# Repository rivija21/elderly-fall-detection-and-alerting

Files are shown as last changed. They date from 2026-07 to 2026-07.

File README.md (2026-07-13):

# Non-Invasive Elderly Fall Detection System

## Overview
This repository contains the firmware, hardware schematics, and mechanical design files for a privacy-preserving, non-invasive bathroom fall detection unit. 

Designed specifically to operate without the use of cameras, this system ensures complete user privacy in sensitive environments. It achieves high-accuracy fall detection by integrating a 60GHz mmWave radar sensor with an ESP32-S3 microcontroller, complemented by a verbal cancellation logic mechanism to rigorously filter false positive alerts.

## Key Features
* **Privacy-First Sensing:** Utilizes 60GHz mmWave radar, eliminating the need for optical cameras.
* **Edge Processing:** All signal processing and fall detection algorithms are executed locally on the ESP32-S3.
* **Verbal Cancellation Logic:** Integrates audio-based confirmation to prevent unnecessary emergency alerts in the event of a false trigger.
* **Custom Enclosure:** 3D-printable housing designed for optimal sensor positioning and environmental protection.

## System Hardware
* **Microcontroller:** ESP32-S3
* **Radar Sensor:** SEN0623 (60GHz mmWave)
* **TPS21 IP2326 based BMS**
* **A impedence matched INMP441 with 4ohm 3W speaker setup**

## Hardware Visuals

### Printed Enclosure
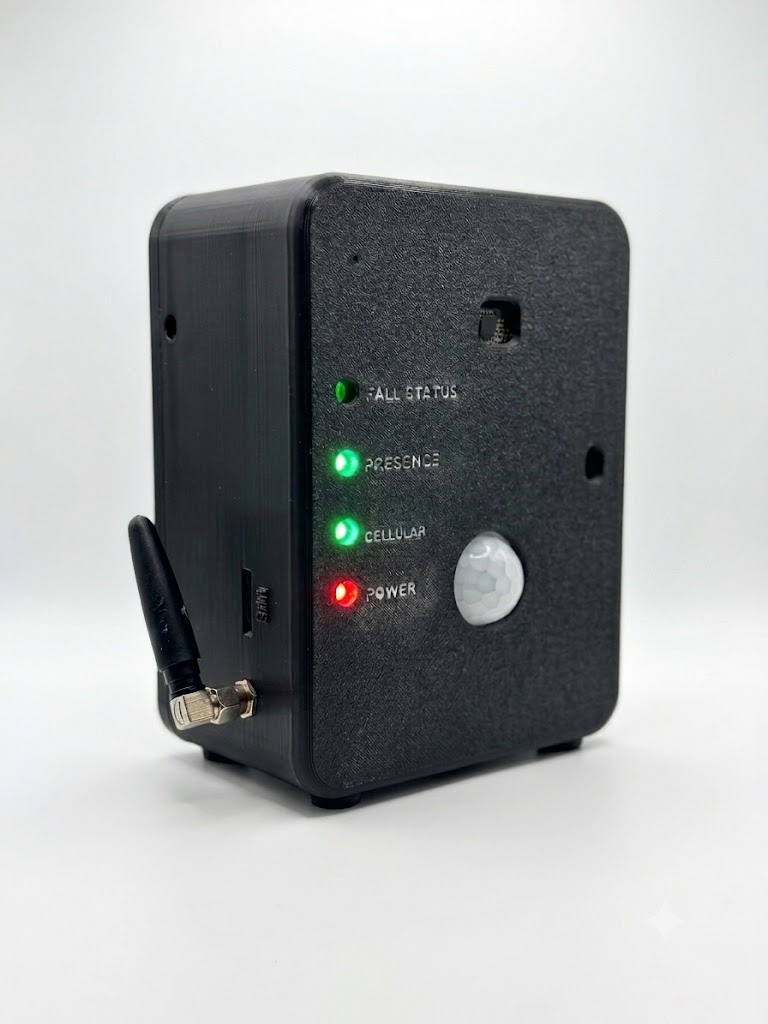
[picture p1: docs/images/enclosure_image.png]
Fully Assembled 3D Printed Enclosure


### PCB Assembly
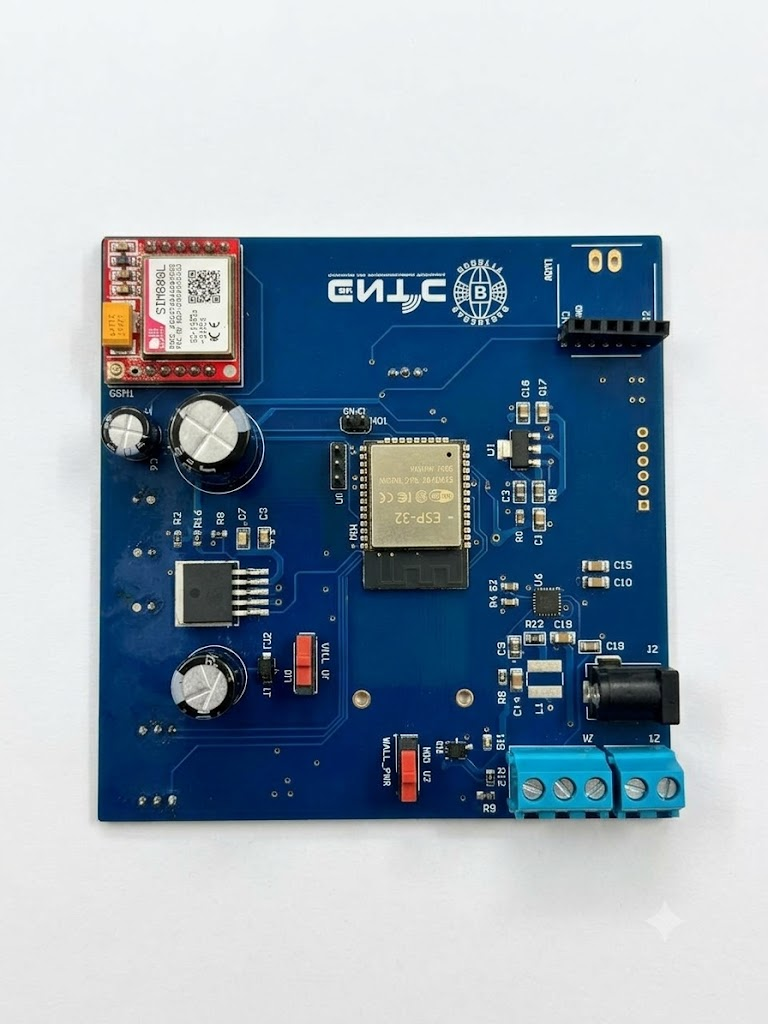
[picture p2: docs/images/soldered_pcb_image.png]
Soldered PCB Configuration


## Repository Structure
```text
elderly-fall-detection/
├── Firmware/       # ESP32-S3 source code and build files
├── Hardware/       # Schematics, PCB layouts, and BOM
├── Mechanical/     # STL files for 3D printing the enclosure
└── Docs/           # Final engineering design project report and diagrams

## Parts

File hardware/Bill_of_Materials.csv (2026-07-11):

Category | Part | Supplier | Qty | Unit Cost (USD) | Bulk Cost (USD) [5000 units]
Microcontroller | ESP32-WROOM-32E | LCSC | 1 | 3.98 | 2.89
Capacitor | 0.1uF | LCSC | 1 | 0.02 | 0.01
Capacitor | 1uF | LCSC | 3 | 0.02 | 0.01
Capacitor | 10uF | LCSC | 4 | 0.04 | 0.03
Capacitor | 22uF | LCSC | 9 | 0.1 | 0.08
Capacitor | 47uF | LCSC | 1 | 0.15 | 0.1
Capacitor | 100uF | LCSC | 1 | 0.5 | 0.3
Capacitor | 330uF | LCSC | 1 | 0.9 | 0.65
Resistor | 100Ω | LCSC | 1 | 0.01 | 0.002
Resistor | 330Ω | LCSC | 2 | 0.01 | 0.002
Resistor | 470Ω | LCSC | 2 | 0.01 | 0.002
Resistor | 1kΩ | LCSC | 1 | 0.01 | 0.002
Resistor | 10kΩ | LCSC | 3 | 0.01 | 0.002
Resistor | 20kΩ | LCSC | 3 | 0.01 | 0.002
Resistor | 33kΩ | LCSC | 1 | 0.01 | 0.002
Resistor | 43kΩ | LCSC | 1 | 0.01 | 0.002
Resistor | 51kΩ | LCSC | 1 | 0.01 | 0.002
Resistor | 100kΩ | LCSC | 3 | 0.01 | 0.002
Resistor | 180kΩ | LCSC | 1 | 0.01 | 0.002
Inductor | 2.2uH | TBD | 1
Connector | 2-hole screw terminal | LCSC | 1 | 0.04 | 0.02
Connector | 3-hole screw terminal | LCSC | 1 | 0.05 | 0.03
Connector | Barrel jack | LCSC | 1 | 0.04 | 0.02
MOSFET | AO341A | LCSC | 1 | 0.02 | 0.01
MOSFET | BSS138 | LCSC | 1 | 0.01 | 0.005
Regulator | MIC2302WU | LCSC | 1 | 0.35 | 0.25
Regulator | AMS1117 | LCSC | 2 | 0.04 | 0.02
IC | TPS2121RUXT | LCSC | 1 | 1.2 | 1
IC | IP2326 | LCSC | 2 | 0.45 | 0.35
LED | NeoPixel strip (8 LEDs) | LCSC | 1 | 1.5 | 0.5
Sensor | MAX98357 | LCSC | 1 | 1.44 | 0.6
Sensor | SIM800L | LCSC | 1 | 3.27 | 1.49
Sensor | HC-SR501 | LCSC | 1 | 0.77 | 0.3
Sensor | SEN0623 | LCSC | 1 | 35 | 21
Sensor | INMP441 | LCSC | 1 | 2.6 | 1
Sensor | VL53L1X | LCSC | 1 | 2.98 | 1.78
Mechanical | Enclosure | MS 3D Printing | 1 | 11.94 | 5.5
PCB | 100x100 mm PCB | JLCPCB | 1 | 5.37 | 2.5
total |  |  |  | 67.07 | 36.375
all prices in USD
tax should also be considered
11/7/2026

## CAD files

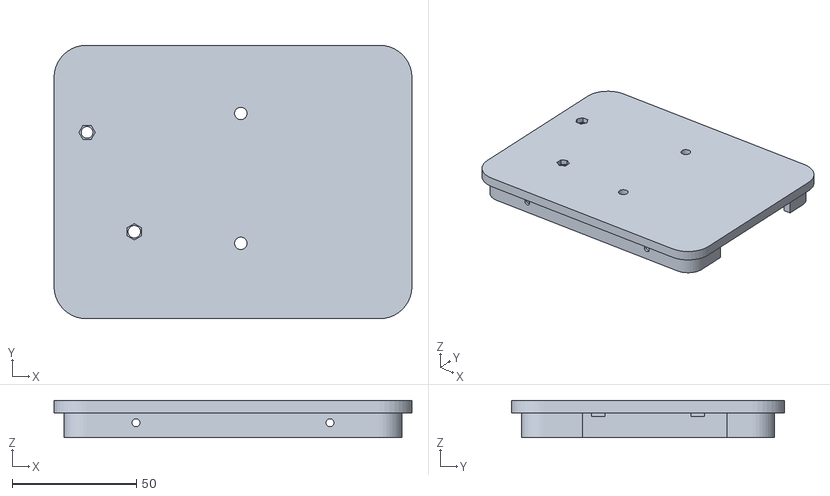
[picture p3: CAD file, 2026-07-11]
mechanical/head.STL
144.0 x 110.0 x 15.0

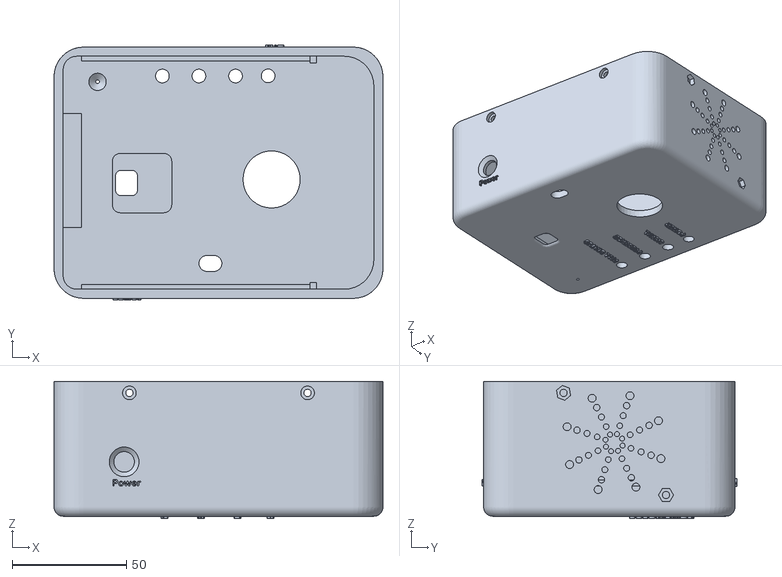
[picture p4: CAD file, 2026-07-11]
mechanical/enclosure.STL
144.0 x 111.8 x 60.0

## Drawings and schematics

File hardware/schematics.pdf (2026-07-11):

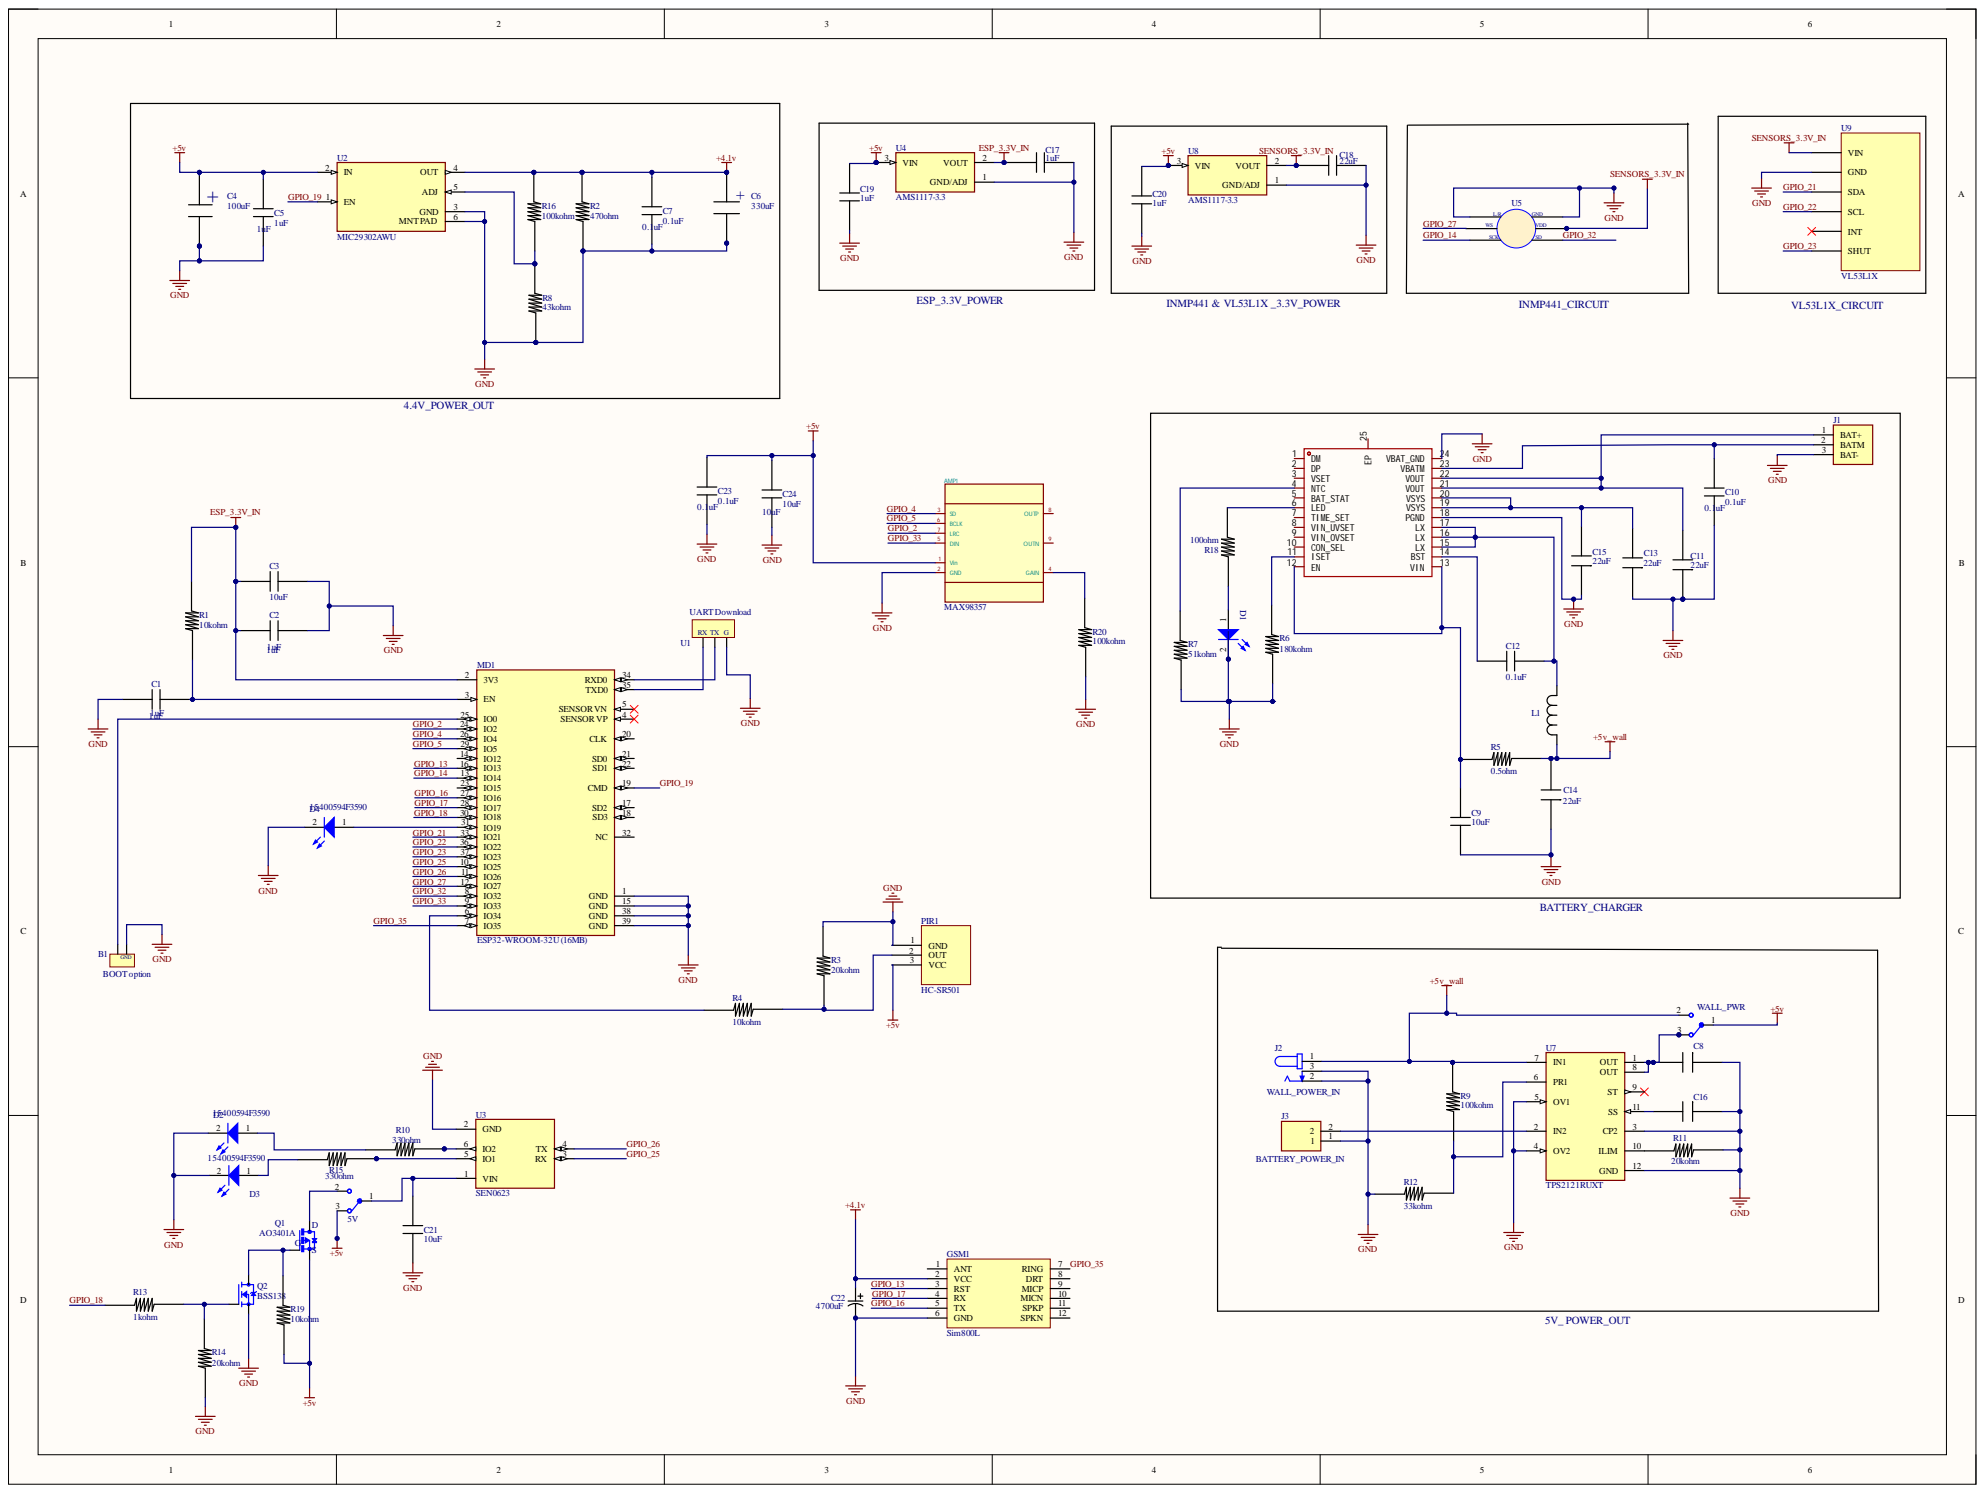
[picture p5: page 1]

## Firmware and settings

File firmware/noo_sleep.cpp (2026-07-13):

#include <Arduino.h>
#include "driver/gpio.h"
#include <DFRobot_HumanDetection.h>
#include <LittleFS.h>
#include "AudioFileSourceLittleFS.h"
#include "AudioGeneratorWAV.h"
#include "AudioOutputI2S.h"
#include <WiFi.h>
#include <Wire.h> //tof
#include "SparkFun_VL53L1X.h"

// --- EDGE IMPULSE & NEOPIXEL INCLUDES ---
#define EIDSP_QUANTIZE_FILTERBANK   0
#include <KalharaHWP-project-1_inferencing.h>
#include "freertos/FreeRTOS.h"
#include "freertos/task.h"
#include "driver/i2s.h"
#include <NeoPixelBus.h>

// Wake-up Pins
#include "driver/rtc_io.h"

#define PIN_PIR        GPIO_NUM_34 // Active HIGH
#define PIN_SIM_RING   GPIO_NUM_35 // Active LOW
// !! -- update the code: sleep/ wake up based on PIR sensor and SIM800L ring detection -- !!
// !! -- use SEN0623 MOSFET gate + otther EN pins and sleep signals for efficient power handling -- !!


// --- PIN DEFS ---
#define PIN_SIM_RING   GPIO_NUM_35 // Active LOW
#define PIN_SIM_EN     GPIO_NUM_21 
#define PIN_RADAR_EN   GPIO_NUM_18

#define SIM_RX_PIN     16 // ESP32 RX2 <- SIM800L TX
#define SIM_TX_PIN     17 // ESP32 TX2 -> SIM800L RX
#define RADAR_RX_PIN   26 // ESP32 RX <- SEN0623 TX
#define RADAR_TX_PIN   25 // ESP32 TX -> SEN0623 RX

// I2S Speaker Output (MAX98357A)
#define I2S_BCLK 5
#define I2S_LRC  2
#define I2S_DIN  33
#define SD_MODE  4

// NeoPixel Configuration
#define NUM_PIXELS 4 
#define DATA_PIN 19 

// --- GLOBAL VARIABLES ---
DFRobot_HumanDetection hu(&Serial1);
NeoPixelBus<NeoGrbFeature, NeoEsp32Rmt0800KbpsMethod> strip(NUM_PIXELS, DATA_PIN);
SFEVL53L1X distanceSensor;

char phone1[15] = "";
char phone2[15] = ""; 
int height = 270;
char location[20] = "bathroom";
volatile bool smsPending = false; 

// --- EDGE IMPULSE GLOBALS ---
typedef struct {
    signed short *buffers[2];
    unsigned char buf_select;
    unsigned char buf_ready;
    unsigned int buf_count;
    unsigned int n_samples;
} inference_t;

static inference_t inference;
static const uint32_t sample_buffer_size = 2048;
static signed short sampleBuffer[sample_buffer_size];
static bool debug_nn = false;
static bool record_status = true;

// --- FUNCTION PROTOTYPES ---
void IRAM_ATTR simRingISR();
void initializesystem();
void handleBathroomOccupancy();
void handleIncomingSMS();
bool verifyFallWithAudio();
void sendSMS(String phoneNumber, String message);
void playAudioFile(const char* filepath);
static bool microphone_inference_start(uint32_t n_samples);
static bool microphone_inference_record(void);
static void microphone_inference_end(void);
static int microphone_audio_signal_get_data(size_t offset, size_t length, float *out_ptr);
static int i2s_init_mic(uint32_t sampling_rate);
static int i2s_deinit_mic(void);
static void capture_samples(void* arg);
static void audio_inference_callback(uint32_t n_bytes);


// --- SETUP & MAIN LOOP ---
void IRAM_ATTR simRingISR() {
    smsPending = true;
}

void setup() {
    Serial.begin(115200);
    delay(100);

    WiFi.mode(WIFI_OFF);
    btStop();

    pinMode(PIN_SIM_RING, INPUT);
    attachInterrupt(digitalPinToInterrupt(PIN_SIM_RING), simRingISR, FALLING);

    strip.Begin();
    strip.ClearTo(RgbColor(0, 0, 0)); 
    strip.SetPixelColor(0, RgbColor(255, 0, 0)); // 4th LED ON (White/Power)
    strip.Show();

    run_classifier_init(); 

    initializesystem();
}

void loop() {
    if (smsPending) {
        smsPending = false;
        handleIncomingSMS();
    }

    if (hu.smHumanData(hu.eHumanPresence) == 1) {
        handleBathroomOccupancy();
    }

    delay(100); 
}

// --- CORE HANDLERS ---
void initializesystem() {
    Wire.begin(); 
    Serial1.begin(115200, SERIAL_8N1, RADAR_RX_PIN, RADAR_TX_PIN);
    delay(100);

    // Initial ToF Measurement for Height
    if (distanceSensor.begin() != 0) {
    } else {
        distanceSensor.startRanging();
        while (!distanceSensor.checkForDataReady()) {
            delay(1);
        }
        int initialDistMm = distanceSensor.getDistance();
        distanceSensor.clearInterrupt();
        distanceSensor.stopRanging();
        
        height = initialDistMm / 10; // Convert mm to cm for SEN0623
    }

    hu.begin(); 
    delay(100);
    delay(1500); 

    while (hu.begin() != 0) {
        delay(1000);
    }

    while (hu.configWorkMode(hu.eFallingMode) != 0) {
        delay(1000);
    }
    delay(300);

    hu.configLEDLight(hu.eFALLLed, 0); delay(300);
    hu.configLEDLight(hu.eHPLed, 0); delay(300);
    hu.dmInstallHeight(height); delay(300); // Utilizes dynamically measured height
    hu.dmFallTime(5); delay(300);
    hu.dmUnmannedTime(5); delay(300);
    hu.dmFallConfig(hu.eResidenceTime, 200); delay(500);
    hu.dmFallConfig(hu.eFallSensitivityC, 3); delay(300);
    hu.sensorRet(); delay(500); 

    Serial2.begin(9600, SERIAL_8N1, SIM_RX_PIN, SIM_TX_PIN);
    Serial.println("Waiting 1s for SIM network registration...");
    delay(1000); 

    Serial2.println("AT+GSMBUSY=1"); delay(500);
    Serial2.println("AT+CMGF=1"); delay(500);
    Serial2.println("AT+CMGD=1,4"); delay(2000);

    Serial2.println("AT+CREG?");
    long cregTimeout = millis() + 2000;
    String cregResponse = "";
    while (millis() < cregTimeout) {
        while (Serial2.available()) {
            cregResponse += (char)Serial2.read();
        }
    }
    if (cregResponse.indexOf(",1") != -1 || cregResponse.indexOf(",5") != -1) {
        strip.SetPixelColor(1, RgbColor(0, 255, 0)); // 3rd LED ON (Green/Cellular OK)
        strip.Show();
    }

    
    if (!LittleFS.begin()) {
    } else {
        if (LittleFS.exists("/setup.wav")) {
            playAudioFile("/setup.wav");
        }
    }
}

void handleBathroomOccupancy() {

    bool isOccupied = true;
    bool fallDetected = false;

    while (isOccupied) {
        int presence = hu.smHumanData(hu.eHumanPresence);
        int fallState = hu.getFallData(hu.eFallState);

        if (presence == 1) {
            strip.SetPixelColor(2, RgbColor(0, 255, 0));
        } else {
            strip.SetPixelColor(2, RgbColor(0, 0, 0));
        }
        strip.Show();

        if (fallState == 1) { 
            fallDetected = true;
            strip.SetPixelColor(3, RgbColor(0, 255, 0)); 
            strip.Show();
            break; 
        }

        if (presence == 0) {
            delay(2000); 
            if (hu.smHumanData(hu.eHumanPresence) == 0) {
                isOccupied = false; 
                fallDetected = false;
            } else {
                Serial.println("False negative mitigated. Occupant still present.");
            }
        }

        if (smsPending) {
            smsPending = false;
            handleIncomingSMS();
            delay(500); 
        }

        delay(1000); 
    }

    if (fallDetected) {
        playAudioFile("/message.wav");

        bool falsePositive = verifyFallWithAudio();
        
        if (!falsePositive) {
            String alertMsg = "ALERT: Fall detected in the " + String(location) + "!";
            
            if (strlen(phone1) > 4) sendSMS(String(phone1), alertMsg);
            if (strlen(phone2) > 4) sendSMS(String(phone2), alertMsg);
            
            if (strlen(phone1) < 5 && strlen(phone2) < 5) {
            }
            delay(5000); 
            
        } else { 
            playAudioFile("/cancel.wav");
        }
        strip.SetPixelColor(3, RgbColor(0, 0, 0)); 
        strip.SetPixelColor(2, RgbColor(0, 0, 0)); 
        strip.Show();
    }
}

bool verifyFallWithAudio() {
    
    if (microphone_inference_start(EI_CLASSIFIER_SLICE_SIZE) == false) {
        Serial.println("ERR: Could not allocate audio buffer. Defaulting to confirmed fall.");
        return false; 
    }

    bool cancellationCommandDetected = false;
    unsigned long verificationStartTime = millis();
    const unsigned long VERIFICATION_TIMEOUT = 10000; 

    while (millis() - verificationStartTime < VERIFICATION_TIMEOUT) {
        if (!microphone_inference_record()) continue;

        signal_t signal;
        signal.total_length = EI_CLASSIFIER_SLICE_SIZE;
        signal.get_data = &microphone_audio_signal_get_data;
        ei_impulse_result_t result = {0};

        EI_IMPULSE_ERROR r = run_classifier_continuous(&signal, &result, debug_nn);
        if (r != EI_IMPULSE_OK) {
            continue;
        }

        if (result.classification[0].value > 0.75) {
            cancellationCommandDetected = true;
            break;
        }
    }

    microphone_inference_end(); 
    return cancellationCommandDetected;
}

void playAudioFile(const char* filepath) {
    if (!LittleFS.exists(filepath)) {
        return;
    }

    pinMode(SD_MODE, OUTPUT);
    digitalWrite(SD_MODE, HIGH); 
    delay(100);

    AudioFileSourceLittleFS *file = new AudioFileSourceLittleFS(filepath); 
    AudioOutputI2S *out = new AudioOutputI2S();
    out->SetPinout(I2S_BCLK, I2S_LRC, I2S_DIN);
    AudioGeneratorWAV *wav = new AudioGeneratorWAV();
    
    if (wav->begin(file, out)) {
        while (wav->isRunning()) {
            if (!wav->loop()) {
                wav->stop();
            }
        }
    } else {
        Serial.println("Failed to decode audio file.");
    }
    
    delete file;
    delete wav;
    delete out;
    
    digitalWrite(SD_MODE, LOW); 
}

void sendSMS(String phoneNumber, String message) {
    phoneNumber.trim(); 
    phoneNumber.replace("\"", ""); 

    while (Serial2.available()) { Serial2.read(); }

    Serial2.print("AT+CMGS=\"");
    Serial2.print(phoneNumber);
    Serial2.print("\"\r"); 
    
    long waitPrompt = millis();
    bool promptReceived = false;
    
    while (millis() - waitPrompt < 3000) {
        while (Serial2.available()) {
            char c = Serial2.read();
            if (c == '>') promptReceived = true;
        }
        if (promptReceived) break;
        delay(10);
    }
    
    if (promptReceived) {
        Serial2.print(message);
        Serial2.write(26); 
        Serial.println("Payload pushed. Waiting 6s...");
        delay(6000); 
    } else {
        Serial.println("Error: SIM timeout.");
        Serial2.write(27); 
        delay(1000);
    }
}

void handleIncomingSMS() {
    delay(1000); 
    Serial2.println("AT+CMGR=1");
    delay(500);
    
    String response = "";
    long timeout = millis() + 3000;
    while (millis() < timeout) {
        while (Serial2.available()) response += (char)Serial2.read();
    }

    String senderNumber = "";
    int cmgrIndex = response.indexOf("+CMGR:");
    if (cmgrIndex != -1) {
        int firstQuote = response.indexOf("\"", cmgrIndex);
        int secondQuote = response.indexOf("\"", firstQuote + 1);
        int thirdQuote = response.indexOf("\"", secondQuote + 1);
        int fourthQuote = response.indexOf("\"", thirdQuote + 1);
        
        if (thirdQuote != -1 && fourthQuote != -1) {
            senderNumber = response.substring(thirdQuote + 1, fourthQuote);
        }
    }

    response.toLowerCase(); 
    bool commandFound = false;
    String replyMessage = ""; 

    // Must evaluate "height=?" prior to "height=" to prevent premature substring matching.
    if (response.indexOf("height=?") != -1) {
        distanceSensor.startRanging(); 
        unsigned long t = millis();
        while (!distanceSensor.checkForDataReady()) {
        if (millis() - t > 1000) {
            replyMessage = "Error: ToF sensor timeout.";
             commandFound = true; 
        } else {
            int currentDistMm = distanceSensor.getDistance(); 
            int currentHeightCm = currentDistMm / 10;
            replyMessage = "Current ToF measured height: " + String(currentHeightCm) + "cm. Active system height: " + String(height) + "cm.";
            commandFound = true;
        }
        distanceSensor.clearInterrupt();
        distanceSensor.stopRanging();
    }   
        int currentDistMm = distanceSensor.getDistance(); 
        distanceSensor.clearInterrupt();
        distanceSensor.stopRanging();
        
        int currentHeightCm = currentDistMm / 10;
        replyMessage = "Current ToF measured height: " + String(currentHeightCm) + "cm. Active system height: " + String(height) + "cm.";
        commandFound = true;
    }
    else if (response.indexOf("height=") != -1) { 
        int valIndex = response.indexOf("height=") + 7;
        int endIndex = response.indexOf('\r', valIndex);
        if (endIndex == -1) endIndex = response.indexOf('\n', valIndex);
        if (endIndex == -1) endIndex = response.length();
        
        height = response.substring(valIndex, endIndex).toInt();
        hu.dmInstallHeight(height); // Pushes the new manual height logic to the mmWave sensor.
        
        replyMessage = "Success: Height manually set to " + String(height) + "cm";
        commandFound = true;
    } 
    else if (response.indexOf("phone1=") != -1) {
        int valIndex = response.indexOf("phone1=") + 7;
        int endIndex = response.indexOf('\r', valIndex);
        if (endIndex == -1) endIndex = response.indexOf('\n', valIndex);
        if (endIndex == -1) endIndex = response.length();
        
        String newPhone = response.substring(valIndex, endIndex);
        newPhone.trim(); newPhone.replace("\"", ""); 
        strncpy(phone1, newPhone.c_str(), sizeof(phone1) - 1);
        phone1[sizeof(phone1) - 1] = '\0'; 
        replyMessage = "Success: Phone1 set to " + String(phone1);
        commandFound = true;
    }
    else if (response.indexOf("phone2=") != -1) {
        int valIndex = response.indexOf("phone2=") + 7;
        int endIndex = response.indexOf('\r', valIndex);
        if (endIndex == -1) endIndex = response.indexOf('\n', valIndex);
        if (endIndex == -1) endIndex = response.length();
        
        String newPhone = response.substring(valIndex, endIndex);
        newPhone.trim(); newPhone.replace("\"", ""); 
        strncpy(phone2, newPhone.c_str(), sizeof(phone2) - 1);
        phone2[sizeof(phone2) - 1] = '\0'; 
        replyMessage = "Success: Phone2 set to " + String(phone2);
        commandFound = true;
    }
    else if (response.indexOf("location=") != -1) {
        int valIndex = response.indexOf("location=") + 9;
        int endIndex = response.indexOf('\r', valIndex);
        if (endIndex == -1) endIndex = response.indexOf('\n', valIndex);
        if (endIndex == -1) endIndex = response.length();
        
        String newLoc = response.substring(valIndex, endIndex);
        newLoc.trim(); newLoc.replace("\"", ""); 
        strncpy(location, newLoc.c_str(), sizeof(location) - 1);
        location[sizeof(location) - 1] = '\0'; 
        replyMessage = "Success: Location set to " + String(location);
        commandFound = true;
    }
    else if (response.indexOf("help") != -1) {
        replyMessage = "CMDs: height=?, height=, phone1=, phone2=, location=, help";
        commandFound = true;
    }
    
    delay(1000);
    if (commandFound) {
        sendSMS(senderNumber, replyMessage);
    } else if (!commandFound && response.length() > 0 && cmgrIndex != -1) {
        sendSMS(senderNumber, "Error: CMD NOT FOUND!");
    }

    while (Serial2.available()) { Serial2.read(); }
    Serial2.println("AT+CMGD=1,4"); 
    delay(3000); 
}

// --- EDGE IMPULSE I2S MICROPHONE HANDLERS ---
static void audio_inference_callback(uint32_t n_bytes) {
    for(int i = 0; i < n_bytes>>1; i++) {
        inference.buffers[inference.buf_select][inference.buf_count++] = sampleBuffer[i];
        if(inference.buf_count >= inference.n_samples) {
            inference.buf_select ^= 1;
            inference.buf_count = 0;
            inference.buf_ready = 1;
        }
    }
}

static void capture_samples(void* arg) {
    const int32_t i2s_bytes_to_read = (uint32_t)arg;
    size_t bytes_read = i2s_bytes_to_read;
    while (record_status) {
        i2s_read((i2s_port_t)1, (void*)sampleBuffer, i2s_bytes_to_read, &bytes_read, 100);
        if (bytes_read > 0) {
            for (int x = 0; x < i2s_bytes_to_read/2; x++) {
                sampleBuffer[x] = (int16_t)(sampleBuffer[x]) * 8;
            }
            if (record_status) {
                audio_inference_callback(i2s_bytes_to_read);
            } else {
                break;
            }
        }
    }
    vTaskDelete(NULL);
}

static bool microphone_inference_start(uint32_t n_samples) {
    inference.buffers[0] = (signed short *)malloc(n_samples * sizeof(signed short));
    if (inference.buffers[0] == NULL) return false;

    inference.buffers[1] = (signed short *)malloc(n_samples * sizeof(signed short));
    if (inference.buffers[1] == NULL) {
        ei_free(inference.buffers[0]);
        return false;
    }

    inference.buf_select = 0;
    inference.buf_count = 0;
    inference.n_samples = n_samples;
    inference.buf_ready = 0;

    if (i2s_init_mic(EI_CLASSIFIER_FREQUENCY)) {
        Serial.println("Failed to start I2S!");
    }
    ei_sleep(100);
    record_status = true;
    xTaskCreate(capture_samples, "CaptureSamples", 1024 * 32, (void*)sample_buffer_size, 10, NULL);
    return true;
}

static bool microphone_inference_record(void) {
    bool ret = true;
    if (inference.buf_ready == 1) {
        ret = false;
    }
    while (inference.buf_ready == 0) {
        delay(1);
    }
    inference.buf_ready = 0;
    return ret;
}

static int microphone_audio_signal_get_data(size_t offset, size_t length, float *out_ptr) {
    numpy::int16_to_float(&inference.buffers[inference.buf_select ^ 1][offset], out_ptr, length);
    return 0;
}

static void microphone_inference_end(void) {
    record_status = false;
    delay(100); 
    i2s_deinit_mic();
    ei_free(inference.buffers[0]);
    ei_free(inference.buffers[1]);
}

static int i2s_init_mic(uint32_t sampling_rate) {
    i2s_config_t i2s_config = {
        .mode = (i2s_mode_t)(I2S_MODE_MASTER | I2S_MODE_RX),
        .sample_rate = EI_CLASSIFIER_FREQUENCY,
        .bits_per_sample = (i2s_bits_per_sample_t)16,
        .channel_format = I2S_CHANNEL_FMT_ONLY_LEFT,
        .communication_format = I2S_COMM_FORMAT_I2S,
        .intr_alloc_flags = 0,
        .dma_buf_count = 8,
        .dma_buf_len = 512,
        .use_apll = false,
        .tx_desc_auto_clear = false,
        .fixed_mclk = -1,
    };
    i2s_pin_config_t pin_config = {
        .bck_io_num = 14,
        .ws_io_num = 27,
        .data_out_num = -1,
        .data_in_num = 32,
    };
    esp_err_t ret = i2s_driver_install((i2s_port_t)1, &i2s_config, 0, NULL);
    ret = i2s_set_pin((i2s_port_t)1, &pin_config);
    ret = i2s_zero_dma_buffer((i2s_port_t)1);
    return int(ret);
}

static int i2s_deinit_mic(void) {
    i2s_driver_uninstall((i2s_port_t)1); 
    return 0;
}

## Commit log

2026-07-11 Initial commit: Add firmware, CAD, schematics, and final EDP report
    [Bill_of_Materials.csv, enclosure.STL, head.STL]
2026-07-11 Fix image paths in README.md
    Updated image paths for printed enclosure and PCB assembly.
2026-07-11 Update enclosure image in README
2026-07-13 bug: comment block wrong syntax for cpp
    [noo_sleep.cpp]
